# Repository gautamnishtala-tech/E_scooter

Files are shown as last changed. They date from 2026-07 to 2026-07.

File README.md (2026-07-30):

<!DOCTYPE html>
<html lang="en">
<head>
<meta charset="utf-8">
<meta name="viewport" content="width=device-width, initial-scale=1">
<body>
<h1>E-Scooter Conversion</h1>

I started this because converting a Razor seemed like a neat thing to try, and then it turned out to have more interesting problems in it than I expected.

The rear wheel was the crux. There's no clean way to get drive torque into a stock Razor wheel, so it had to be replaced with something I could key to an axle — which meant printing a wheel, printing the tire separately in TPU, and epoxying the two together. Everything else followed from that: the new axle needed cross-drilling for set screws, the sprocket needed a printed mount and a shaft flange, and the motor's final position ended up being decided by chain geometry rather than by me.

None of the individual steps are difficult. Working out the order they have to happen in, and which dimensions depend on which, was most of the work.

So this is the approach I landed on, written down while it's still fresh.

Converting a Razor A5 Lux kick scooter into a chain-driven electric scooter using a 24 V brushed DC motor, an off-the-shelf motor controller, and two 3D-printed parts.

</body>
</html>

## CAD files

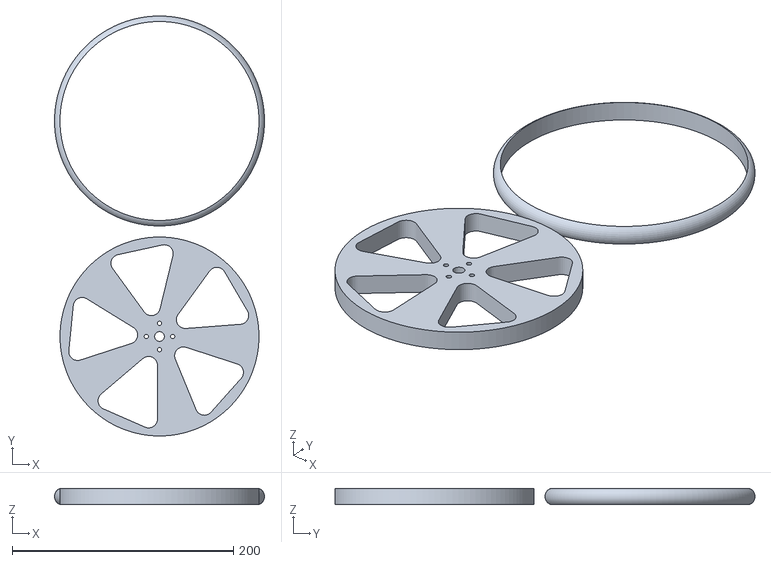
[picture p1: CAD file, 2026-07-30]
wheel+tirefinal.stl
190.0 x 380.0 x 14.6

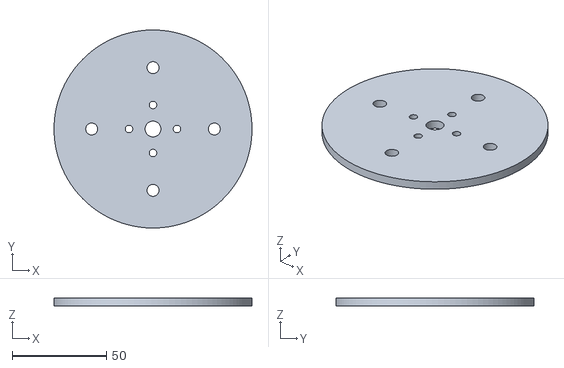
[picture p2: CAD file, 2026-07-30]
gearmountfinal.stl
105.0 x 105.0 x 4.00

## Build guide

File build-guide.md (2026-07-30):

<h1>Mounting the rear wheel to new Axle</h1>
<ol>
  <li>Remove rear wheel <a href="https://www.youtube.com/watch?v=sMZBpMj_JZo">How to Replace the Wheels on the Razor Carbon Lux Kick Scooter</a> 0:39-2:05</li>
  <li>Cut axle to 5.5 in</li>
  <li>Drill a hole 1 in in from the end of the axle</li>
  <li>Drill another hole 2 &frac38; in from the other end of the axle</li>
  <li>3D print the wheel in PLA with 100% infill then 3D print the tire in TPU.</li>
  <li>Add lots of Epoxy to the outer rim of the wheel then slide the tire over the wheel and let epoxy dry and harder for 24h</li>
  <li>Attach flange to wheel using the #6-32x5/8&rsquo;&rsquo; screws and the lock nuts.</li>
  <li>Slide the axle through the frame then the wheel then the frame again leaving the hole that is 1 in away from the axle sticking out on the right side.</li>
  <li>Align the wheel in the middle of the frame then attach the collars to either side of the frame so the axle does not slide</li>
  <li>Attach the set screw that goes through the flange then have it go through the hole on the axle</li>
</ol>

<h1>Mounting the gear to the axle</h1>
<ol>
  <li>3D print the gear mount in PLA 100% infill</li>
  <li>Then using the screws and nuts that came with the gear, mount the gear to the gearmount</li>
  <li>Mount the flange to the gear mount so that the screws are in the same direction as the screws for the gear.</li>
  <li>Slide the gear with everything on it with the flange side down</li>
  <li>Use the set screws to screw it in to the axle</li>
</ol>

<h1>Wiring the Electronics</h1>
<ol>
  <li>To the end of the motor solder the male end of the connector (the opposite of the one in the esc).</li>
  <li>Using the attachment piece on the battery, attach the female end of the connector (the one opposite the battery port on the esc).</li>
  <li>Plug the motor (blue and yellow wire) and battery (black and red wire) in to the esc then plug the key ignition in to the power locks end of the esc (pink and blue)</li>
  <li>Attach the thumb throttle to the plug it came with then solder the 3 port plug with the opposite end of the one on the throttle then plug that in</li>
</ol>

<h1>Mounting the Motor and adding the Chain</h1>
<ol>
  <li>Cut the chain to 97 links</li>
  <li>Rest the motor on the bed of the scooter and attach the chain to the motor and the gear</li>
  <li>Find a spot where the chain is straight and taught</li>
  <li>Mark the spot of the holes in the mounting bracket to the frame</li>
  <li>Drill the frame</li>
  <li>Add the screws to the motor but the screws are going upward then add the nuts and tighten</li>
  <li>Loop the chain around the motor and the gear</li>
  <li>Using velcro or double sided tape, attach the motor and esc to the scooter</li>
  <li>Take out the handle bar for the side you want the thumb throttle to be on.</li>
  <li>Cut the string then slide in the thumb throttle</li>
  <li>Reattach the handle bar and using tape wrap excess slack</li>
  <li>Using tape stick the ignition to the frame</li>
</ol>

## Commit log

2026-07-30 Update README.md
    Converted README from Markdown to HTML format and added detailed instructions for mounting components and wiring electronics for the E-scooter conversion.
2026-07-30 Remove assembly instructions from README
    Removed detailed assembly instructions for mounting components and wiring electronics.
2026-07-30 Add build guide for scooter modifications
    This document provides a detailed guide for mounting the rear wheel, gear, wiring electronics, and motor installation for a scooter.
